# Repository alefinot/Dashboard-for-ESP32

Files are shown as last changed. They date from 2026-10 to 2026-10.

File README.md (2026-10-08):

# Dashboard++ for ESP32





[]()

**Dashboard++** is an ultra-high-performance, production-grade automotive digital instrument cluster and telemetry solution designed for motorcycles, cars, and custom electric/combustion vehicles powered by the **ESP32 WROOM-32** dual-core microcontroller.

Featuring a 4.0-inch ILI9488 TFT display (480×320 resolution) driven over a 60 MHz SPI bus using **LovyanGFX** with PROGMEM-mapped VLW fonts, Dashboard++ blends real-time multi-sensor fusion algorithms, sprite-based anti-aliased digit rendering, dirty-rendering optimizations, hysteresis-based dynamic CPU frequency scaling, persistent NVS configuration management, an Open-Meteo live weather widget, and a complete single-page Web application served over WiFi with REST API control, NVS backup/restore, and automatic cloud OTA pull.

---

## Technical Table of Contents
1. [Executive Overview](#executive-overview)
2. [System Architecture & Task Allocation](#system-architecture--task-allocation)
3. [Hardware Component Specifications](#hardware-component-specifications)
4. [Hardware Pinout Matrix](#hardware-pinout-matrix)
5. [Software Architecture & Mathematical Models](#software-architecture--mathematical-models)
   - [Dual-Source Speed Fusion & Odometer Engine](#1-dual-source-speed-fusion--odometer-engine)
   - [Anti-Aliased GFX Engine & 7-Segment Fonts](#2-anti-aliased-gfx-engine--7-segment-fonts)
   - [Piecewise Linear Fuel Calibration & Filtering](#3-piecewise-linear-fuel-calibration--filtering)
   - [Steinhart-Hart Coolant Temperature Math](#4-steinhart-hart-coolant-temperature-math)
   - [Fuel Economy & Performance Drag Timer](#5-fuel-economy--performance-drag-timer)
   - [Power Management & Dynamic CPU Scaling](#6-power-management--dynamic-cpu-scaling)
6. [Embedded Web UI & REST API Reference](#embedded-web-ui--rest-api-reference)
7. [NVS Configuration Parameter Reference](#nvs-configuration-parameter-reference)
8. [Codebase Architecture & File Map](#codebase-architecture--file-map)
9. [Build, Installation & Flashing Guide](#build-installation--flashing-guide)
10. [Simulation & Demo Mode](#simulation--demo-mode)
11. [License & Credits](#license--credits)

---

## Executive Overview

Dashboard++ replaces legacy analog or basic digital gauges with an automotive-grade telemetry console. Key capabilities include:

- **Dual Speed Fusion (Hall Effect + GNSS):** Dynamically fuses microsecond-level hardware interrupt pulses with NMEA GPS speed vectors, adjusting confidence based on satellite lock quality ($N_{\text{sat}}$) and cross-checking delta errors.
- **Sprite-Based Anti-Aliased Speed Rendering:** The main speed readout is pre-rendered to an off-screen LGFX_Sprite using a 120px VLW 7-segment digital font, then pushed to the display in a single DMA transfer — reducing SPI bus contention and eliminating per-digit draw calls.
- **PROGMEM VLW Font System:** All fonts (Conthrax SemiBold and DS-DIGIT variants) are compiled into flash as PROGMEM byte arrays (generated from the `.vlw` sources in `data/Fonts/` by `scripts/vlw_to_header.py`), loaded at build time via `loadVLWFont()` — zero DRAM per glyph, no runtime filesystem lookups.
- **Dirty-Rendering Frame Pipeline:** Element state tracking ensures only mutated visual regions are drawn to the SPI bus, with dedicated per-element refresh rate throttles for speed, satellite count, timer, battery, fuel economy, and average speed.
- **Configurable 7-Segment Digital Fonts:** 120px (sprite) and 28px (direct) seven-segment fonts with background "ghost digit" rendering (888 backdrop effect) and fully user-configurable integer and decimal digit boundaries for all telemetry counters.
- **Full Sensor Suite Integration:** Precise fuel level monitoring (20-point piecewise linear calibration table + EMA filtering), engine coolant thermistor telemetry (Steinhart-Hart equation), battery voltage divider monitoring, trip fuel economy tracking, **trip average speed**, and a **session max speed (Vmax)** readout display.
- **FreeRTOS Dual-Core Multitasking:** Strict core isolation — the continuous ~1.1KB/s GNSS UART stream is quarantined in its own Core 0 task (bulk ring-buffer read, bounded per tick, sitting below the WiFi stack), while the vehicle sensor suite and UI rendering run on Core 1, so a GPS stream backlog can never stall the dashboard or freeze any real-time value.
- **Embedded Web Management Portal:** Embedded single-page Web application accessible over SoftAP or local WiFi network featuring grouped card-based configuration UI with live search, real-time performance telemetry panel (FPS, CPU frequency/temp, RAM, flash storage), interactive sliders, color pickers, NVS backup/restore, web serial terminal stream, cloud OTA pull, and HTTP file upload OTA firmware updating.
- **Hysteresis-Based Dynamic CPU Scaling:** Three-state frequency governor (240/160/80 MHz) with hysteresis deadbands prevents oscillation, and thermal throttling automatically caps frequency at configurable warning/critical temperature thresholds.

---

## System Architecture & Task Allocation

The system leverages the ESP32's Xtensa dual-core processor via FreeRTOS tasks to guarantee deterministic sensor sampling without visual stuttering or UI delays.

```
┌─────────────────────────────────────────────────────────────────────────────────┐
│                            ESP32 WROOM-32 DUAL-CORE                             │
├────────────────────────────────────────┼────────────────────────────────────────┤
│    CORE 0  (GNSS Stream & Network)     │  CORE 1  (Vehicle Sensors & Display)   │
├────────────────────────────────────────┼────────────────────────────────────────┤
│┌──────────────────────────────────────┐│┌──────────────────────────────────────┐│
││ Task: GpsTaskCore0 (Prio 2, 10KB)    │││ Task: SensorTaskCore1 (Prio 2, 10KB) ││
││                                      │││                                      ││
││• UART2 @ 115200 bulk ring drain      │││• Hall Sensor GPIO33 ISR              ││
││  (readBytes() batch, 1024 B/tick cap)│││• ADC: Fuel (32), Temp (36), Bat (35) ││
││• TinyGPS++ NMEA + UBX NAV-PVT parse  │││• Fuel Economy & Accel Timer          ││
││• Speed Fusion & Odometer calc        │││• Trip Average Speed                  ││
││• GNSS Epoch Time Sync -> settimeofday│││• Safe Thread Sync via g_stateMutex   ││
││• Safe Thread Sync via g_stateMutex   │││                                      ││
││                                      │││• Safe Thread Sync via g_stateMutex   ││
││──────────────────────────────────────│││──────────────────────────────────────││
││ Task: WebTaskCore0 (Prio 1, 12KB)    │││ Main Loop (Priority 1)               ││
││                                      │││                                      ││
││• SoftAP (Dashboard_Config) & STA     │││• Dirty-Rendering Frame Pipeline      ││
││• WebServer HTTP Handlers             │││• LovyanGFX SPI Driver (60 MHz)       ││
││• ArduinoOTA Firmware Listener        │││• Sprite-Based Speed (120px VLW)      ││
││• Serial Log Streaming API            │││• Hysteresis CPU Scaling (80/160/240) ││
│└──────────────────────────────────────┘││• Auto Night-Mode Backlight PWM       ││
│                                        ││• Ignition Deep Sleep State Machine   ││
│                                        ││• Telemetry Logging to 4KB Ring       ││
│                                        │└──────────────────────────────────────┘│
└─────────────────────────────────────────────────────────────────────────────────┘
```

> [!NOTE]
> The GNSS task sits on Core 0 **below** the WiFi/HTTPD/LWIP stack on purpose: the module streams
> ~1.1KB/s continuously and the drain is I/O-gated at the byte arrival rate, so it can never
> out-run the stream. GPS is 1Hz-tolerant data, so if the network preempts the drain, only GPS
> values lag — the vehicle sensors and the screen are never touched.

> [!NOTE]
> The **weather fetch task** (Core 0, spawned by `startWeatherFetch()` on Core 1) polls the Open-Meteo
> API on a configurable interval (`WEATHER_REFRESH_MIN`) and stores the result in a dedicated
> `g_weatherData` struct. A 30 s guard asks a stuck fetch to abort (the fetch polls
> `weatherAbort` at its checkpoints and HTTP calls carry 8 s connect/read timeouts) so it unwinds
> and deletes itself rather than being killed with `vTaskDelete()`; while an aborted fetch is still
> alive, `startWeatherFetch()` refuses to stack a second one. A config save triggers an
> instant refetch with a 2 s retry backoff.

> [!NOTE]
> Every FreeRTOS task is started through `startTask()` in `src/main.cpp`, which checks the
> `xTaskCreatePinnedToCore()` return value, retries once on half the requested stack (a reduced
> stack usually fits and beats a missing subsystem) and, if that fails too, records the task in a
> `failedTasksMask` and logs it with the free heap. A task that cannot start is therefore named in
> the boot log instead of silently missing — the failure that used to show up only as a frozen
> heartbeat, no Web UI or dead sensors.

---

## Hardware Component Specifications

| Component | Part / Model | Protocol / Signal | Specifications |
| :--- | :--- | :--- | :--- |
| **Microcontroller** | ESP32-WROOM-32 | Xtensa 32-bit LX6 | Dual-core 240 MHz, 520 KB SRAM, 4 MB SPI Flash, RTC IO |
| **Display Panel** | ILI9488 TFT LCD (4.0") | SPI3 (16-bit RGB565) — SCLK GPIO18, MOSI GPIO23, CS GPIO5, DC GPIO27, RST GPIO14 (no MISO) | 480×320 pixels, 60 MHz SPI bus speed (clamped to 1–80 MHz), hardware CS/DC/RST |
| **Display Backlight** | LED Backlight (`BL_DISPLAY`, GPIO12) | LEDC PWM — pin-based `ledcAttach(BL_DISPLAY, 1000, 8)` | 1 kHz hardware PWM, 8-bit resolution (256 brightness levels), logarithmic fading; the LEDC channel is assigned by the arduino-esp32 3.x wrapper |
| **GNSS Module** | BZGNSS P25 Pro (u-blox M10) | UART2 (RX=GPIO16, TX=GPIO17) | 115200 baud (configurable), UBX NAV-PVT / NMEA 0183 stream (module is preconfigured — the firmware is receive-only), 10 Hz update rate, multi-constellation (GPS/GLONASS/BDS/Galileo), UTC epoch time synchronization |
| **Wheel Speed Sensor** | Hall Effect Interrupt | GPIO33 (Input Pullup) | Any-edge ISR stamps the edges; interval/filter logic runs on the sensor task, microsecond timing |
| **Fuel Level Sensor** | Marine Resistive Sender (capacitive touch removed in v1.3.6) | GPIO32 (ADC1_CH4) | Voltage divider behind an excitation resistor, ohm-domain calibration table (up to 20 points), oversampling + EMA smoothing, open/short detection |
| **Engine Temp Sensor** | NTC Thermistor (10k/100k) | GPIO36 (ADC1_CH0) | Analog 0–3.3V, Steinhart-Hart equation, voltage divider balance |
| **Battery Voltage** | Voltage Divider (5.7:1) | GPIO35 (ADC1_CH7) | Analog 0–3.3V, range 0–18.8V DC, sampled every 500 ms |
| **Power / Ignition** | Ignition Key Sense Line | GPIO4 | High=Ignition ON, Low=Power Lost → Animated Deep Sleep |

---

## Hardware Pinout Matrix

> For the board side of the same information — which connector/plug each signal lives on,
> with the connector pin numbers and the small-part roles — see
> [`hardware/PINOUT.md`](hardware/PINOUT.md).

| ESP32 Pin | Function Name | Peripheral Type | Signal Direction | Hardware Configuration & Notes |
| :---: | :--- | :--- | :---: | :--- |
| **GPIO0** | BOOT | Factory Reset | Input (Pullup) | `pinMode(0, INPUT_PULLUP)`; **hold BOOT 4 s, release, hold 4 s again** within the first 30 s after boot to wipe the config — the reliable path. The release in the middle is required because GPIO0 is shared with the serial adapter's DTR line through the auto-reset transistor: a PC that holds DTR asserted keeps GPIO0 low forever, and the old single 8 s hold wiped the config on every boot with nobody touching the board. The serial fallback (send `RESET` within the first 2 s of boot) is matched against a rolling 32-character window, so boot-log echo can no longer fill the capture and hide the command (issue #39) |
| **GPIO1** | Console TX | Debug Console | Output | `Serial.setPins(1, 3)` pins the console explicitly (arduino-esp32 3.x moved the UART1 default to GPIO26/27) |
| **GPIO3** | Console RX | Debug Console | Input | Same `Serial.setPins(1, 3)` call |
| **GPIO4** | `POWER_SENSE_PIN` | Power Sense | Input (No Pull) | Ignition sense line; triggers EXT0 RTC wake up from deep sleep |
| **GPIO5** | `CS_DISPLAY` | SPI Chip Select | Output | Hardware SPI CS for ILI9488 Display |
| **GPIO12** | `BL_DISPLAY` | Backlight PWM | Output | Pin-based `ledcAttach(BL_DISPLAY, 1000, 8)` — 1 kHz PWM, 8-bit resolution |
| **GPIO14** | `SPI_RST` | Display Reset | Output | Active-Low hardware reset line for ILI9488 |
| **GPIO16** | `GNSS_UART2_RX_PIN` | GPS Serial RX (UART2) | Input | Connected to the GNSS module TX pin. Receive-only: the firmware never transmits to the module |
| **GPIO17** | `GNSS_UART2_TX_PIN` | GPS Serial TX (UART2) | Output | Connected to the GNSS module RX pin; configured but idle - no UBX command is ever sent |
| **GPIO18** | `cfg.pin_sclk` | SPI Clock | Output | Hardcoded in `gfx.cpp` (SPI3_HOST), 60 MHz default |
| **GPIO23** | `cfg.pin_mosi` | SPI Master Out | Output | Hardcoded in `gfx.cpp`, LCD data/command stream |
| **GPIO25** | `TRIP_RESET_PIN` | Trip Reset Button | Input (Pullup) | Momentary push button to GND; hold `TRIP_RESET_HOLD_MS` to zero the trip stats (issue #17). Internal ~45 kΩ pull-up, no external parts |
| **GPIO27** | `SPI_DC` | Data / Command | Output | High = Data, Low = Command for ILI9488 controller |
| **GPIO32** | `FUEL_TOUCH_PIN` | Fuel sender input | Input | Dedicated ADC1 Channel 4 pin: 3V3 → `FUEL_EXC_RES_OHM` → GPIO32 → sender → tank ground (capacitive touch removed in v1.3.6) |
| **GPIO33** | `HALL_SENSOR_PIN` | Hall Interrupt | Input (Pullup) | Any-edge (`CHANGE`) hardware interrupt: the ISR timestamps both transitions, the filter chain validates them on the sensor task |
| **GPIO34** | `LIGHT_SENSOR_PIN` | Ambient Light | Input (No Pull) | LDR ambient light sensor for auto-brightness (calibrated via `/api/ambient/cal-dark` / `cal-bright`) |
| **GPIO35** | `BATTERY_SENSE_PIN` | Battery ADC | Input (No Pull) | Connected to 5.7:1 precision resistor divider node |
| **GPIO36** | `TEMP_SENSE_PIN` | Engine Temp ADC | Input (No Pull) | Connected to NTC thermistor / balance resistor divider node |

> [!IMPORTANT]
> GPIO32 is dedicated to the fuel ADC input to avoid pin-sharing conflicts with the GPIO33 Hall interrupt hardware line.

> [!NOTE]
> This matrix matches the code (`src/dashboard.h` pin defines and the hardcoded display SPI pins in `src/gfx.cpp`), which is the source of truth. The GNSS serial pair moved from GPIO25/26 to **GPIO16/17** during the pin-swap test and stayed there, which is what freed **GPIO25** for the trip-reset button; **GPIO26** stays free as the spare for a second button. Strapping pins (`GPIO0`, `GPIO2`, `GPIO5` = `CS_DISPLAY`, MTDI/`GPIO12`, MTDO/`GPIO15`) are deliberately not used for buttons — a button to GND can hold them the wrong way during reset and block boot. The display SPI bus has no MISO line (`cfg.pin_miso = -1`), and GPIO21/22 (former compass I²C) are unused.

---

## Software Architecture & Mathematical Models

### 1. Dual-Source Speed Fusion & Odometer Engine

Dashboard++ features a dual-source speed calculation engine that combines low-latency wheel rotation timing with absolute satellite GPS telemetry.

#### Hall Sensor Calculation & 5-Layer Defense Pipeline
Speed is derived from microsecond timing between consecutive interrupt pulses on GPIO33, protected by an end-to-end 5-layer defense pipeline that eliminates spark ignition EMI glitches, prevents baseline collapse during deceleration, and bounds rate-of-change to physical limits:

1. **Layer 1: Measured Pulse-Width Qualification (Glitch Filter):** Real wheel magnets hold GPIO33 LOW for hundreds of microseconds (one revolution at 200 km/h is still 29.7 ms long). High-frequency ignition coil ringing collapses back to HIGH within <10 µs. The GPIO ISR used to prove the width by busy-waiting `HALL_PULSE_MIN_US` and re-sampling `REG_READ(GPIO_IN1_REG)` **inside** the interrupt, which masked interrupts on that core for up to 1 ms per glitch (~86 bytes of GNSS RX at 115200 baud). Now the interrupt is `CHANGE` (both edges), the ISR only stamps the transition time into a 64-slot ring, and the qualification is *measured*: `rise − fall ≥ HALL_PULSE_MIN_US` (default 150 µs, WebUI-tunable, clamped to 10…1000 µs). A glitch is dropped before any interval logic runs, exactly as before, and the ISR stays at roughly a microsecond. Ring overflow drops the newest edge and is counted as `drop=` in the `HALL:` telemetry line; the accept latency is reported as `lag=`.
2. **Layer 2: Anti-Collapse Timing Baseline (Integer Guard) + Period Guard:** 100% integer timestamping and period guard with zero floating-point math, in the validation step that runs on the sensor task (`processHallEdges()`). When actively rolling, candidate intervals faster than $2\times$ previous speed ($gap \times 2 < last$) are dropped without updating `lastHallPulseTimeUs` or the stable baseline `hallStableIntervalUs`. This prevents spark bursts during braking from collapsing the guard baseline and producing >200 km/h spikes. The complementary upper bound is `HALL_PERIOD_GUARD`: an interval more than $N\times$ the last accepted one is dropped too (a wheel cannot slow $N$-fold in a single revolution; a genuine stop is handled by Layer 3 instead). $N = 1$ disables it.
3. **Layer 3: Standstill Detection, Buffer Purge & Deceleration Decay:** If time since the last pulse exceeds `STANDSTILL_TIMEOUT_US` (1.5 s), the wheel was stopped. The first pulse synchronizes the timing baseline, holds its odometer credit until a confirming pulse follows, and completely purges the history ring buffer. During deceleration, if elapsed time $dt$ since the last pulse exceeds $1.5\times$ the rotation period (plus the recorded accept latency `lag`, so deferred validation cannot make an on-time pulse look overdue), dynamic decay constrains speed smoothly to 0 km/h without mid-revolution diving.
   - **Layer 3b: Confirmed-Roll Speed Gate:** the purge in Layer 3 also disarms Layer 2 (which is conditioned on the rolling state) and leaves the median window with a single sample, so before this gate *one* accepted inter-edge gap became the displayed speed — two ignition-EMI edges 12 ms…1.5 s apart on a parked machine reported a plausible reading (100 ms → 59 km/h on a 1650 mm wheel). The speed output now stays at 0 until `HALL_CONFIRM_REVS` (3) consecutive accepted intervals agree pairwise within $2\times$ — the same physical bound Layer 2 uses while rolling. Cost: a genuine roll start is displayed two revolutions later (≈0.6 s at 12 km/h, ≈0.2 s at 30 km/h). Distance credits are unaffected (the odometer is guarded by the pending-anchor logic). Below ~4 km/h the 1.5 s standstill timeout already reports 0, so the usable low-speed floor does not change.
4. **Layer 4: Physical Slew-Rate Limiter (Max Accel / Decel):** Terrestrial motorcycles cannot exceed physical acceleration limits (~1.7g / 60 km/h/s) or emergency braking (~2.3g / 80 km/h/s). Clamping $\Delta V$ between update ticks (~20 ms) mathematically prevents instantaneous multi-hundred km/h jumps on the speedometer.
5. **Layer 5: Sensor Fusion Outlier Rejection:** In Sensor Fusion mode (2), if Hall speed reads $> V_{\text{gps}} + 30\text{ km/h}$ while GPS has a solid satellite lock, the Hall reading is rejected as an anomalous spike and the dashboard displays GPS speed.

#### Speed Source & Fusion Logic
The displayed speed source is selected by `SPEED_SOURCE_MODE`: `0`=Hall only, `1`=GPS only, `2`=Sensor Fusion (default).

In **Sensor Fusion mode (2)**, the engine dynamically balances both sensors:
- **Rock-Solid Standstill:** When $V_{\text{hall}} = 0$ and $V_{\text{gps}} < \text{GPS\_START\_KMH}$ (3.0 km/h), speed is forced to solid `0.0 km/h`, eliminating GPS drift at traffic lights.
- **Immediate Response:** As soon as wheel pulses arrive ($V_{\text{hall}} > 0$), speed is displayed immediately without clamping.
- **Dynamic Throttle Tracking:** When $|V_{\text{gps}} - V_{\text{hall}}| > \text{MAX\_SPEED\_DELTA\_KMH}$ (such as normal GPS lag during rapid acceleration), Hall is trusted directly so throttle response is never suppressed.
- **Dual Failsafe Redundancy:** If the Hall sensor fails or disconnects at speed, the system automatically falls back to valid GPS ($V_{\text{gps}} \ge 3.0\text{ km/h}$). If GPS signal is lost in a tunnel, Hall sensor carries 100% of the speed. Speed never drops to 0 while moving.
- **Dynamic Confidence Blending:** When both sensors are healthy and consistent ($\Delta V \le \text{MAX\_SPEED\_DELTA\_KMH}$):
$$C_{\text{sat}} = \text{constrain}\left(\frac{N_{\text{sat}} - N_{\text{min}} + 1}{N_{\text{opt}} - N_{\text{min}} + 1}, 0.0, 1.0\right)$$
$$C_{\delta} = \text{constrain}\left(1.0 - \frac{\Delta V - \Delta V_{\text{min}}}{\Delta V_{\text{max}} - \Delta V_{\text{min}}}, 0.0, 1.0\right)$$
$$W_{\text{gps}} = C_{\text{sat}} \cdot C_{\delta} \cdot 0.5$$
$$V_{\text{fused}} = (W_{\text{gps}} \cdot V_{\text{gps}}) + ((1 - W_{\text{gps}}) \cdot V_{\text{hall}})$$
Capping $W_{\text{gps}}$ at 0.5 ensures Hall sensor's zero-latency dynamic throttle/brake response is always preserved, while GPS anchors long-term tire wear accuracy.

#### Odometer Persistence Strategy
To protect the ESP32 NVS Flash memory from wear, distance accumulation runs continuously in RAM. The odometer writes to non-volatile storage **only after accumulating a full 1.0 km increment**:
$$\Delta D_{\text{ram}} \ge 1.0\text{ km} \implies \text{Preferences.putDouble("odo", } D_{\text{total}}\text{)}$$

**Sharing the odometer across cores.** The odometer is a 64-bit `double`, and a 64-bit load/store on ESP32 is two 32-bit bus cycles: a read that lands between the two halves of a write returns a mixture of two different distances. The totals therefore live file-local in `src/sensors.cpp` and every other task reaches them through the locked accessors `odoGet()`, `odoSet()`, `odoAdd()` (read-modify-write in one critical section), `odoLastSaved()` and `odoMarkSaved()`, guarded by a dedicated spinlock (`odoMux`) — deliberately *not* `g_stateMutex`, so the display never waits behind sensor or NVS work and the critical sections stay a few instructions long. The accessors never write flash; the 1 km wear discipline above is unchanged.

#### UBX Frame Parser (receive-only)

The module streams UBX and NMEA on the same UART, so `src/sensors.cpp` runs a byte-at-a-time state machine (`ubxParseByte`) alongside TinyGPS++: it locks onto `0xB5 0x62`, reads class/id/length, seeds both Fletcher-8 accumulators by stepping through each header byte individually, and hands a checksum-valid NAV-PVT to the NMEA side. It never transmits anything (see the receive-only rule).

- **Length is honoured, including zero.** A zero-length payload goes straight to the checksum states — entering the payload state with `len = 0` used to consume `CK_A`/`CK_B` as payload, corrupt the accumulators and raise a spurious `CKFAIL`, leaving the parser to resync by luck on the next `0xB5` (issue #33).
- **Oversize frames are dropped at the header** (`len > 92`) rather than overflowing the payload buffer, and a bad checksum drops exactly one frame before resyncing.
- **Counters, not silence:** `ubxSyncSeen`, `ubxCkFail`, `ubxOversize` are reported in the GPS debug telemetry so a framing problem is visible instead of looking like lost satellites.
- **Checked offline:** `python scripts/verify_ubx_parser.py` runs a host replica of the state machine against hand-built frames — NAV-PVT (92 B), ACK (10 B), zero-length, poisoned checksum, garbage/false-sync, oversize, back-to-back frames — and asserts that the old zero-length path still fails, so the regression cannot come back unnoticed.

---

### 2. Anti-Aliased GFX Engine & 7-Segment Fonts

Graphics rendering is built on `LovyanGFX` with specialized antialiasing routines and a PROGMEM-mapped VLW font system (compiled into flash — no runtime filesystem lookups, zero DRAM per glyph).

#### Text Bounds Contract (`getTextBounds`)

`LGFX_ST7789_4::getTextBounds()` (declared in `src/dashboard.h`, defined in `src/gfx.cpp`) reports **advance-based** bounds, not ink bounds: `w` is `textWidth()` (the advance the string consumes), `h` is the font line height, `y1` is `-baseline`, and **`x1` is always `0` by contract** (issue #44). Every layout path — 7-segment digit cells, the weather/accel badges, the centred splash and signature strings — places text on advances, and the `- x1` terms those expressions carry are the documented slot where a real per-glyph left bearing would flow through, not a live correction. Code must not treat `x1` as a measured bearing; if ink bounds are ever needed, a separate helper gets added rather than these semantics changing. The `digitXOff[]` / `ds15_digitXOff[]` tables fed from it are therefore advance-only offsets by construction.

#### Alpha Blending Math
Sub-pixel anti-aliased primitives draw edges with fractional coverage $\alpha \in [0, 1]$. Color blending uses fast integer arithmetic:
$$R_{\text{out}} = \lfloor (R_{\text{bg}} \cdot (256 - a) + R_{\text{fg}} \cdot a) \gg 8 \rfloor$$
$$G_{\text{out}} = \lfloor (G_{\text{bg}} \cdot (256 - a) + G_{\text{fg}} \cdot a) \gg 8 \rfloor$$
$$B_{\text{out}} = \lfloor (B_{\text{bg}} \cdot (256 - a) + B_{\text{fg}} \cdot a) \gg 8 \rfloor$$

#### Sprite-Based Speed Rendering
The main speed display is rendered to an off-screen `LGFX_Sprite` using the VLW 120px 7-segment digital font. Ghost digits (888 backdrop) and active digits are drawn once per frame into the sprite, then pushed to the display in a single DMA transfer — drastically reducing SPI bus transactions compared to per-digit draw calls.

#### VLW Font System
All typography is compiled into flash as PROGMEM byte arrays (`include/*.h`, generated from the `.vlw` sources in `data/Fonts/` by `scripts/vlw_to_header.py`):
- `DS-DIGIT_120px.vlw` → `DS_DIGIT_120px_vlw.h` — Main speed readout (sprite-rendered)
- `DS-DIGIT_28px.vlw` → `DS_DIGIT_28px_vlw.h` — Secondary digits (time, odometer, satellite, battery, fuel economy, average speed)
- `Conthrax_SemiBold_28px.vlw` → `Conthrax_SemiBold_28px_vlw.h` — Section headers and badges
- `Conthrax_SemiBold_16px.vlw` → `Conthrax_SemiBold_16px_vlw.h` — Unit labels and sidebar text
- `Conthrax_SemiBold_10px.vlw` → `Conthrax_SemiBold_10px_vlw.h` — Micro labels (AVG badge, IST badge)

Legacy compiled-in GFX font bitmaps (`Conthrax_SemiBold4pt7b`, `Conthrax_SemiBold7pt7b`) are retained as fallbacks for the badge/label sizes.

---

### 3. Marine Resistive Fuel Sender: Divider, Ohm-Domain Table & Filtering

Fuel level is read from a standard marine resistive sender wired as a voltage
divider on `FUEL_TOUCH_PIN` (GPIO32). The capacitive pad this input used to carry
is gone; the pin is now a plain ADC input (issue #18):

```
3V3 ─── FUEL_EXC_RES_OHM ─── GPIO32 (ADC1_CH4) ─── sender ─── tank ground
```

#### From ADC code to ohms
`FUEL_OVERSAMPLE` conversions are averaged into a raw code $\bar{S}$ (software
oversampling — the core exposes no hardware averaging for this pin), turned into
a voltage with `FUEL_ADC_VREF` (the 3.3 V rail — since issue #55 it is not a Web
UI field any more), and the sender resistance is recovered from the divider:

$$V = V_{\text{ref}} \cdot \frac{R_{\text{sender}}}{R_{\text{sender}} + R_{\text{exc}}} \qquad\Rightarrow\qquad R_{\text{sender}} = R_{\text{exc}} \cdot \frac{V}{V_{\text{ref}} - V}$$

The calibration table (`fuelCalOhms`) stores **ohms, not ADC codes**. That is
what makes any sender standard work on the same firmware — SAE **10–180 Ω**
(low = empty), European/VDO **240–33 Ω** (high = empty), GM **0–90 Ω** — and it
means a captured table still means the same thing after the excitation resistor
(or the sender) is swapped. `FUEL_OHM_EMPTY` / `FUEL_OHM_FULL` describe the
sender: they size the exciter, define the fault band, and pre-fill the table
ramp; they do not replace the table.

#### EMA + piecewise interpolation
Smoothing stays in the ADC-code domain (linear, and the same domain the table was
captured against), then the ohm value walks the table:
$$\bar{S}_t = (\alpha \cdot S_t) + ((1 - \alpha) \cdot \bar{S}_{t-1}) \qquad \alpha = \texttt{FUEL\_FILTER\_ALPHA}\ (default{=}0.08)$$
Given $N$ table points $T[0 \dots N-1]$ mapped to tank slots $0 \dots N-1$, find
segment $i$ containing $R_{\text{sender}}$:
$$L_{\text{fuel}} = i + \left(\frac{R_{\text{sender}} - T[i]}{T[i+1] - T[i]}\right)$$
$$\text{FuelPercentage} = \text{constrain}\left(\left\lfloor \frac{L_{\text{fuel}}}{N - 1} \times 100 \right\rfloor, 0, 100\right)$$

The traversal direction is taken from the table's two ends, so a rising (SAE) and
a falling (European) sender are both handled without a mode switch.

#### Sender fault detection
The failure that makes a self-built sender useless is an open line that still
looks like a plausible reading, so the input is classified every sample and shown
in the Web UI instead of being turned into a tank level:

| Condition | Reported as |
| :--- | :--- |
| `FUEL_INPUT_ENABLED` off | **no input** — gauge pinned at 0, a floating pin never invents a level |
| pin within 0.5 % of the rail, or $R > 3 \times$ the entered full/empty maximum | **open circuit** — sender unplugged, wire broken, arm off the pivot |
| $R$ below `min(EMPTY, FULL)` by more than `max(5 Ω, 25 %)` | **shorted input** — signal wire on ground |

Demo mode drives the same pipeline: the simulated level is converted back through
the calibration table into a divider code and read forward again, so the table,
divider math and fault band are exercised with no hardware fitted (rule 20).

#### Excitation resistor sizing
$R_{\text{exc}}$ is a trade: the geometric mean of the sender range spreads the
span over the most volts, but pushes more current through the sender element. The
Web UI suggests the best E12 value for the entered range under a **15 mA** sender
current budget and keeps the top of the span below 2.6 V, because a reading
pinned near the rail is indistinguishable from an open circuit. For the shipped
10–180 Ω default that suggestion is 220 Ω — the same value the firmware ships
with — giving a 1.34 V span at 14.3 mA.

Check the whole chain on a host with `python scripts/verify_fuel_ohms.py`
(divider round-trip, both conventions, resolution per tank slot, demo round-trip,
fault band, exciter suggestion).

---

### 4. Steinhart-Hart Coolant Temperature Math

Engine temperature is measured via an NTC thermistor connected in a resistor divider configuration with a balance resistor $R_{\text{balance}}$ (default=10,000 $\Omega$).

#### Voltage Divider Resistance Calculation
$$V_{\text{out}} = \text{ADC}_{\text{raw}} \times \left(\frac{3.3}{4095}\right)$$
$$R_{\text{ntc}} = R_{\text{balance}} \times \left(\frac{V_{\text{out}}}{3.3 - V_{\text{out}}}\right)$$

#### Steinhart-Hart B-Parameter Equation
$$T_{\text{Kelvin}} = \left( \frac{1}{\beta} \cdot \ln\left(\frac{R_{\text{ntc}}}{R_{\text{room}}}\right) + \frac{1}{T_{\text{room}}} \right)^{-1}$$
$$T_{\text{Celsius}} = T_{\text{Kelvin}} - 273.15$$
where $R_{\text{room}} =$ `NTC_R25` (default=10,000 $\Omega$), $T_{\text{room}} = 298.15\text{ K}$ ($25^\circ\text{C}$), and $\beta =$ `NTC_BETA` (default=3950). A fixed `NTC_TEMP_OFFSET` (°C, default=0.0) is added to the result to correct a systematic reading bias.

#### WebUI Sensor Calibration
The **Sensors Tuning** WebUI card calibrates the two analog sensors against a reference, using the live `/api/live` snapshot the page polls once per second (no raw-ADC conversion needed):
- **Fuel level Sensor** — the live sender resistance (Ω) is shown next to a fault state (`open` / `shorted` / `out of range` / `no sender`). Two ways to build the table (`fuelCalOhms`): **Fill from empty/full ohm** pre-fills a linear ramp from `FUEL_OHM_EMPTY` to `FUEL_OHM_FULL` (a good start, no driving needed), or drive the tank through its levels and **Capture** the live reading into each slot — slot `0` = empty, slot `N-1` = full. Changing the point count regenerates the ramp. The card is titled without the pin number (issue #55), and the excitation-resistor suggestion is computed from the empty/full ohms on the page plus the fixed 3.3 V rail.
- **Speedometer** — `SPEED_SOURCE_MODE`, `SPEED_SOURCE_HOLD_MS`, the two hall-vs-GPS deviation bands (`GPS_MIN_DEV_KMH`, `MAX_SPEED_DELTA_KMH`), the GPS start/stop pair (`GPS_START_KMH`, `GPS_STOP_SETTLE_MS`) and the wheel-signal filters (`HALL_MEDIAN_SAMPLES`, `HALL_PERIOD_GUARD`, `HALL_PULSE_MIN_US`), in that order (issue #56). The GNSS hardware rows (baud, satellite counts) stay in the GPS block.
- **Engine Temperature** — the live reading is shown; type a reference temperature and press **Apply** to set `NTC_TEMP_OFFSET`. `NTC_R25`, `NTC_R_BALANCE` and `NTC_BETA` are under **Advanced**.
- **Battery Voltage** — the live reading is shown; type a reference voltage (e.g. a multimeter) and press **Apply** to set `BATTERY_OFFSET`. `BATTERY_SCALE` (divider ratio) is under **Advanced**.
- Calibrating against a live reading means no raw-ADC arithmetic in the browser: the offset is derived on the device from the value it is currently seeing.

---

### 5. Fuel Economy & Performance Drag Timer

#### Instantaneous & Trip Fuel Economy
- **Trip Average (KM/L):** $KM/L_{\text{avg}} = \frac{D_{\text{trip}}}{C_{\text{consumed}}}$. The trip is zeroed only by an explicit trip reset — the physical button on GPIO25, `POST /api/trip/reset`, or a factory reset — never by a detected refuel (issue #17). A fuel-level rise still re-anchors the consumption baseline so the average stays sane, but it leaves the trip distance and the averages alone.
- **Instantaneous (KM/L):** Calculated across a 3-second sliding window:
  $$KM/L_{\text{inst}} = 0.4 \cdot \left(\frac{\Delta D_{3\text{s}}}{\Delta C_{3\text{s}}}\right) + 0.6 \cdot KM/L_{\text{inst, prev}}$$
- **Trip Average Speed (KM/H):** $V_{\text{avg}} = \frac{D_{\text{trip}}}{t_{\text{elapsed}}}$, displayed in the bottom row alongside fuel economy readouts.
- **Session Max Speed (Vmax):** The highest fused/filtered speed reached this power-on session; held on screen until the next reboot (RAM-only, no NVS persistence, no manual reset). Rendered as the **MAX** icon in the bottom row — same 28px 7-segment structure as the Instant KM/L readout — in MPH under imperial. Controlled by `SHOW_ELEMENT_MAX_SPEED`, `OFFSET_MAX_SPEED_X/Y`, `ALIGN_MAX_SPEED`, `MAX_SPEED_INT_DIGITS`, `MAX_SPEED_DEC_DIGITS`, and the `REFRESH_MAX_SPEED_MS` redraw throttle.

#### Acceleration Performance Timer
Measures time taken to accelerate between configured speed thresholds (`ACCEL_START_SPEED` to `ACCEL_TARGET_SPEED`, e.g., 0–50 km/h or 0–100 km/h) using a 3-state state machine with configurable timeout (`ACCEL_MAX_TIME`, default=30s):

```
  ┌─────────┐    Speed >= StartSpeed     ┌─────────┐
  │  READY  │ ─────────────────────────> │ RUNNING │
  └─────────┘                            └─────────┘
       ▲                                      │
       │ Speed < Start (Reset)                │ Speed >= TargetSpeed OR Timeout
       └──────────────────────────────────────┼───────────────────────┐
                                               ▼                       │
                                         ┌──────────┐                  │
                                         │ FINISHED │ <────────────────┘
                                         └──────────┘
```

---

### 6. Power Management & Dynamic CPU Scaling

To balance processing performance, power consumption, and thermal stability, Dashboard++ includes dynamic CPU management and ignition sensing.

#### Hysteresis Dynamic Scaling Matrix

The governor uses a 3-state machine with hysteresis deadbands to prevent frequency oscillation:

```
                      ┌──────────────────────────────┐
                      │ Read Current Measured FPS &  │
                      │ Die Temp (temperatureRead()) │
                      └──────────────┬───────────────┘
                                     │
                     Is ENABLE_DYNAMIC_CPU true?
                     ├─── NO  ──> Set MANUAL_CPU_FREQ (80 / 160 / 240 MHz)
                     └─── YES ──> Check current state:
                                    ├── State = 240 MHz:
                                    │    └── FPS > 85% Target → 160 MHz
                                    │    └── else → stay at 240 MHz
                                    ├── State = 160 MHz:
                                    │    ├── FPS < 65% Target → 240 MHz
                                    │    ├── FPS > 95% Target → 80 MHz
                                    │    └── else → stay at 160 MHz
                                    └── State = 80 MHz:
                                         ├── FPS < 45% Target → 240 MHz
                                         ├── FPS < 70% Target → 160 MHz
                                         └── else → stay at 80 MHz
                                    │
                                    └── Apply Thermal Throttling:
                                          ├── Temp >= CRIT (70°C): Force 80 MHz
                                          └── Temp >= WARN (60°C): Cap at 160 MHz
```

#### Ignition Loss & Deep Sleep Transition
When `ENABLE_POWER_SENSE` is enabled and `POWER_SENSE_PIN` (GPIO4) stays **continuously LOW for `POWER_SENSE_OFF_MS`** (default 10 s, 500–120000 ms):
1. Plays goodbye screen animation (`showGoodbyeScreen(true)`).
2. Fades display backlight down to 0% via LEDC PWM.
3. Configures RTC EXT0 wake-up trigger on GPIO4 (High level).
4. Invokes `esp_deep_sleep_start()`.

The line is debounced in software (`powerSenseOffConfirmed()` in `src/sensors.cpp`): the timer restarts on every HIGH, so ignition bounce, a load-dump dip or a flaky ground of a few milliseconds up to several seconds cannot stall the GPS/odometer task or put the unit to sleep (issue #26). A single LOW sample used to be enough. Side effect: key-off costs `POWER_SENSE_OFF_MS` of live current draw before the goodbye screen and sleep; wake behaviour is unchanged (EXT0 on GPIO4 going HIGH).

---

## Embedded Web UI & REST API Reference

Dashboard++ embeds a single-page management portal directly into flash memory (`index_html`).

### WiFi Network Connectivity
- **SoftAP Mode:** Emits AP SSID `Dashboard_Config` (Default IP: `192.168.4.1`). Always up alongside the client connection (`WIFI_AP_STA`), secured by `AP_PASSWORD` (empty or 8–63 characters).
- **Multi-SSID Client Mode:** Stores up to 5 networks. They are tried in slot order, and the search **never expires** — a failed cycle is simply followed by another one, forever (there is no search-policy parameter to set). The order is **automatic**: when a network joins, it is moved to slot 0, so the network this unit actually reached last is the first one tried after a reboot or a dropout — no hand-ordered “primary / fallback 1…4”. Credentials are only ever removed by an explicit **Forget**; being out of range is the normal state for a vehicle and never deletes a network by itself.
- **Phone-style network picker (Web UI → Network → Wifi):** press **Scan Networks**, tap the network, type the passphrase once. Open networks join without a password, a network that is already stored reconnects without asking for it again, and a hidden network is added by name. The scan is a cached list of the 30 strongest SSIDs (channels 1–13); it is never refreshed automatically, because a scan moves the radio off its working channel — it runs when asked and after a failed search cycle. With all five slots full the device refuses to guess: the UI asks which stored network may be replaced.

> [!IMPORTANT]
> **Access model (deliberate).** The config portal and the REST API have **no login** — access control is the Wi-Fi itself. `AP_PASSWORD` must be empty or 8–63 characters; a shorter value is rejected and the default (`12345678`) is restored, so the hotspot can never come up with a password the ESP32 silently refused. **Change that default before using the dashboard on a public network**: anyone who joins the hotspot (or reaches the dashboard's LAN IP) can change settings and flash firmware.

### Web UI Features
The management portal features a modern grouped card-based layout:
- **Collapsible sections** with smooth accordion animations (non-JS fallback)
- **Live search bar** to filter configuration parameters across all sections
- **Autosave** triggered 2 seconds after any input change
- **Visible checkboxes** (UI Layout → Screen Elements) control only what is drawn on the display; sensors, GPS, odometer and every calculation keep running whether the element is visible or not, so hiding a readout never stops the data behind it
- **Advanced Mode** switch in the header reveals the technical parameters, so the common setup path stays short (see `ADV_MODE`)
- **Color pickers** with inline preview for all UI color values
- **Slider + number inputs** with mouse-wheel scroll protection for all range parameters
- **XY offset controls** with linked sliders for UI element positioning
- **Real-time performance panel** displaying FPS, CPU frequency/temperature, RAM usage, flash storage utilization, and live serial output monitor
- **Weather Widget group** with city, latitude/longitude, refresh interval, locale, and a day/night icon
- **Ambient light calibration** (dark / bright reference points)
- **Cloud OTA pull** controls (enable, URL) with live status polling
- **OTA firmware upload** via file picker
- **NVS backup/restore** (export downloads `GET /api/config` as `dashboard_backup.json`, import posts it back to `POST /api/config`)

### REST API Endpoints

| Endpoint | Method | Description | Request Payload / Params | Content-Type |
| :--- | :---: | :--- | :--- | :--- |
| `/` | `GET` | Serves pre-gzipped single-page Web UI | None | `text/html` |
| `/debug` | `GET` | Dump first bytes of the pre-gzipped UI buffer (build sanity check) | None | `text/plain` |
| `/api/config` | `GET` | Exports complete NVS configuration plus read-only `build_version` | None | `application/json` |
| `/api/config` | `POST` | Updates NVS parameters and applies changes; on a save where N values could not be written the answer carries `nvsErrors: N`, `nvsFailedKeys: "KEY,…"` and `nvsAvailable` (free NVS entries) | Config JSON object | `application/json` |
| `/api/wifi/scan` | `GET` | Cached Wi-Fi scan plus the stored networks: `scanning`, `ageMs`, `count`, `max: 30`, `nets[]` (`ssid`, `rssi`, `ch`, `auth`, `authName`, `saved`) and `saved[]` (`slot`, `ssid`, `connected`). Reading it never touches the radio | None | `application/json` |
| `/api/wifi/scan` | `POST` | Queues a background scan of channels 1–13 (the radio leaves its channel for a few seconds, which is why the firmware never scans on its own); poll `GET` for the result | None | `application/json` (`{"status":"requested"}` / `{"status":"scanning"}`) |
| `/api/wifi/join` | `POST` | Stores one network and searches for it immediately. An SSID already stored keeps its slot (with no `pass` field the stored passphrase is reused, not blanked); otherwise the first free slot is used. With all five taken the answer is `status:"full"` plus the stored list, and re-sending with `"slot":n` names the network to displace | `{"ssid":"…","pass":"…"}` — `pass` omitted = reuse stored / open network; `"slot":n` = overwrite that slot | `application/json` (`status`, `slot`, `ssid`, `nvsOk`, `overwrite`) |
| `/api/wifi/forget` | `POST` | Removes one stored network from RAM and NVS and restarts the search. Credentials are never dropped by the device on its own | `{"slot":n}` (0–4) | `application/json` (`status`, `slot`, `ssid`, `nvsOk`) |
| `/api/time` | `POST` | Syncs system clock from browser | JSON body `{"timestamp":1700000000}` (integer epoch s; must fall in 2020–2100) | `application/json` (`{"status":"ok"}` / `400` with reason when out of range) |
| `/api/odo` | `GET` | Reads odometer distance in km | None | `application/json` |
| `/api/odo` | `POST` | Sets odometer distance | `{"km": 123.45}` | `application/json` |
| `/api/trip/reset` | `POST` | Zeros the trip stats (same reset as the GPIO25 button); the odometer and session max speed are untouched | None | `application/json` |
| `/api/reboot` | `POST` | Triggers graceful device restart | None | `text/plain` |
| `/api/sleep` | `POST` | Triggers immediate deep sleep | None | `text/plain` |
| `/api/reset` | `POST` | Factory reset — clears the `cfg` namespace; WiFi credentials and the odometer survive | None | `text/plain` |
| `/api/ambient` | `GET` | Reads raw ambient light sensor value | None | `application/json` |
| `/api/sensors` | `GET` | Reads calibrated battery voltage (`v`) and coolant temperature (`t`) | None | `application/json` |
| `/api/fuel` | `GET` | Reads the fuel input: `raw` averaged ADC code, `liters`, `pct`, `ohm` sender resistance, `st` input state (0 = disabled, 1 = ok, 2 = open circuit, 3 = shorted) | None | `application/json` |
| `/api/live` | `GET` | Single 1 Hz snapshot for the Web UI's live readings: `ambient`, `odo` (km), `fuel_raw`, `fuel_ohm`, `fuel_st`, `volts`, `temp`. One response feeds all five cells, so they always show the same instant | None | `application/json` |
| `/api/ambient/cal-dark` | `POST` | Sets dark-reference ambient light value (auto-brightness floor) | None | `application/json` (`{"status":"ok"\|"saved-ram-only","value":N}` — `saved-ram-only` means the value is applied but the NVS write failed) |
| `/api/ambient/cal-bright` | `POST` | Sets bright-reference ambient light value (auto-brightness ceiling) | None | `application/json` (same shape as `cal-dark`) |
| `/api/ota` | `POST` | Over-The-Air firmware binary upload | Binary `.bin` payload | `multipart/form-data` |
| `/api/ota/pull` | `POST` | Triggers cloud OTA pull (checks `OTA_PULL_URL`) | None | `text/plain` |
| `/api/ota/check` | `GET` | Reports cloud OTA pull state (`enabled`, `url`, `current_version`, `build_version`, `version_override`, `previous_version`, `status`) | None | `application/json` |
| `/api/serial` | `GET` | Streams internal 4 KB ring buffer logs | None | `text/plain` |
| `/api/perf` | `GET` | Live telemetry (CPU, Heap, task stack headroom, FPS, WiFi, partitions), plus the web task's own timing: `web_serve_ms_last` / `web_serve_ms_max` (what one `handleClient()` pass costs) and `web_slow_iters` (loop iterations over 100 ms) | None | `application/json` |
| `/api/health` | `GET` | Health probe: heap, FPS, partition layout and the NVS entry budget (`nvs_bytes`, `nvs_entries_used` / `_available` / `_total`) | None | `application/json` |
| `/api/boot` | `GET` | Boot/reboot forensics (reset reason, storm, last-reboot tag, heap watermark). `reset_reason` covers the whole core enum — `POWERON`, `EXT`, `SW (clean restart)`, `PANIC (crash/abort)`, `INT_WDT`, `TASK_WDT`, `WDT (other)`, `DEEP_SLEEP_WAKE`, `BROWNOUT`, `SDIO`, `USB`, `JTAG`, `EFUSE_ERR`, `PWR_GLITCH`, `CPU_LOCKUP`, `UNKNOWN`; anything unmapped prints `RST_<n>` (issue #42) | None | `application/json` |

---

## NVS Configuration Parameter Reference

Dashboard++ keeps every configuration parameter as one row of a single table, `CFG_TABLE` in `src/config.cpp`: the C++ global, the JSON key, the NVS key, the default, the allowed band and the kind (`CK_INT` / `CK_UINT` / `CK_FLT` / `CK_BOOL` / `CK_STR` / `CK_SECRET`) all on one line. `processConfig()` walks that table in its three modes — boot load, JSON serialize (`GET /api/config`) and restore/save (`POST /api/config`) — across 197 parameters (192 regular + 5 WiFi secrets), plus the fuel-calibration table kept beside it.

### Numeric Range Validation (issue #21)

Every numeric parameter carries an explicit **known-good band** in its `CFG_TABLE` row in `src/config.cpp` (`lo`/`hi` for `CK_INT` / `CK_UINT`, `flo`/`fhi` for `CK_FLT`) — that table is the single source of truth. The band is enforced on **all three write paths** (boot load, `POST /api/config`, and config restore): an out-of-range value is **clamped to the nearest end of the band, logged by name, and the clamped value is what gets written to NVS** — a bad value never reaches the running system, and a restore is never rejected outright because one field is off.

- **Non-finite floats** (`nan`, `inf`) fall back to the parameter's default rather than poisoning a calculation.
- **Cross-field rules** are repaired after the per-field clamps, in one place (`sanitizeConfigPairs()`): `TEMP_BAR_MIN < TEMP_BAR_MAX`, `TEMP_BAR_MIN <= TEMP_WARN_LOW <= TEMP_WARN_YEL <= TEMP_WARN_RED <= TEMP_BAR_MAX` (the three temp color fade points, repaired cold→hot so a band can never flip direction), `FUEL_WARN_RED <= FUEL_WARN_YEL` (fuel is mirrored — it turns red *below* its marker), `LIGHT_SENSOR_DARK_VAL < LIGHT_SENSOR_BRIGHT_VAL`, `MIN_SATELLITES <= OPTIMAL_SATELLITES`, `CPU_THROTTLE_TEMP_WARN <= CPU_THROTTLE_TEMP_CRIT`.
- **Enumerated parameters** are snapped to the nearest legal step: `GPS_BAUD` to a standard u-blox rate (1200…921600), `MANUAL_CPU_FREQ` to 80 / 160 / 240 MHz. `DISPLAY_ROTATION` is masked to 0–3, `WHEEL_CIRCUMFERENCE_MM` has always been floored at 1 (it is a divisor).
- **Fuel calibration table** (`fuelCalOhms`) cells are clamped to the sender band 0–100000 Ω on load and on restore. The table is in **ohms** since issue #18 (it used to be raw ADC codes under the name `touchTable`); old `touchTable` values in a backup are ignored rather than re-injected as ohms. The table is also required to be **monotonic in one direction** (the direction its first and last entries already imply): out-of-order points are sorted by `repairFuelTable()` on boot load and on save, written back to NVS, and named in the log, because a gap in the ramp would otherwise freeze the needle (issue #19). The gauge walk in `src/sensors.cpp` carries a second layer — a reading that matches no segment parks on the nearer end and logs once every 5 s instead of leaving the last value in place.
- The **WebUI mirrors the same bands** so a bad entry is caught before it is posted: numeric inputs get `min`/`max` from a `FIRMWARE_LIMITS` table generated out of `config.cpp` (`python scripts/make_webui_limits.py` regenerates it after any band change), an out-of-range entry is corrected in the box and listed in the save message, and an emptied numeric box falls back to its default instead of posting a blank (which the device used to read as `0`).

Bands are also checked offline by `python scripts/verify_config_ranges.py`: every numeric parameter must have a band, no shipped default may fall outside its own band, and the cross-field rules must hold for the factory values.

### NVS Access, Locking & Write Errors (issue #32)

ESP-IDF's NVS layer has its own internal locking, so a torn write is unlikely — what is *not* protected is the session. Two tasks opening and closing the same namespace independently can still collide: one task's `end()` closes the handle the other is still using, which comes back as `ESP_ERR_NVS_*` from `putInt()`/`putString()` and shows up as a setting that quietly reverted after a reboot. The old code took `prefsMux` at some call sites and not at others, so the protection depended on which file the code happened to live in.

- Every namespace open now goes through **`NvsSession`** (`src/dashboard.h`): an RAII wrapper that holds `prefsMux` for the whole `begin()`/`end()` pair, logs when a namespace cannot be opened, and closes on scope exit so an early return cannot leak the handle. It skips the lock while `prefsMux` is still `NULL` (early boot, single-threaded). The long-lived `preferences` object for the `dashboard` namespace keeps its explicit `prefsMux` pairs.
- **Write results are checked.** `nvsWriteFailed(key, esp_err_t)` logs the failing key with `esp_err_to_name()`; the table-driven save counts them (`cfgApply()` bumps `cfgNvsWriteErrors` for every row that fails) and a save ends with `Config save: N parameter(s) failed to reach NVS … they will revert on reboot` instead of pretending nothing happened. The same check covers the fuel-table writes, the factory-reset credential restore, the bootinfo writes and the ambient calibrations.
- **A failed read is not a default.** Where an unreadable NVS would previously have produced "no value" and triggered a factory seed, the seed is now skipped with a log line — a flash that cannot be read must never be answered by overwriting it.
- **Factory defaults are the table.** On first boot (`CFG_VER` missing or below 5) the seed writes each `CFG_TABLE` default straight into NVS and RAM (`cfgSeedDefaults()`, one `NvsSession` for the whole pass) — there is no second copy of the defaults in flash and no `JsonDocument` to build one. The WiFi credentials are deliberately not seeded, so a lost `CFG_VER` stamp can never strand a unit without a network, and the fuel ramp is rebuilt from the seeded `FUEL_OHM_EMPTY`/`FUEL_OHM_FULL` only when the stored table is not already the factory ramp.
- `prefsMux` is a plain (non-recursive) mutex: nothing inside a locked NVS region may open NVS itself.

### Key Configuration Categories

#### System & Performance
- `TARGET_FPS` (default=60): Desired display refresh rate, **5–120 FPS** (band-checked on load and in the Web UI). It sets the derived `DISPLAY_REFRESH_MS` frame budget (120 → 8 ms, 60 → 16 ms, 5 → 200 ms); values above what the SPI panel can carry simply drop the FPS counter rather than saturating the display core (issue #36).
- `SPI_BUS_SPEED` (default=60000000): SPI bus frequency in Hz. Accepted range **1000000–80000000** (1–80 MHz; WebUI shows MHz). Out-of-range values are clamped on load/save — a `0` or a negative (wrapped) value would otherwise feed LovyanGFX a degenerate clock divider and blank the panel. The read clock is derived as `SPI_BUS_SPEED × 8/5`, computed in 64-bit and clamped to the same band.
- `ENABLE_DYNAMIC_CPU` (default=false): Toggles automatic CPU frequency scaling (hysteresis-based).
- `MANUAL_CPU_FREQ` (default=240): Fixed CPU clock frequency (80, 160, or 240 MHz) used when `ENABLE_DYNAMIC_CPU` is off. The value is snapped to the nearest legal step, and every `setCpuFrequencyMhz()` call now checks its result — a refused switch logs `CPU: refused to switch to …MHz` instead of claiming a frequency the chip never switched to (issue #34).
- `ENABLE_CPU_THROTTLE` (default=true): Enables thermal frequency capping.
- `CPU_THROTTLE_TEMP_WARN` (default=60): Warning temperature threshold in °C.
- `CPU_THROTTLE_TEMP_CRIT` (default=70): Critical temperature threshold in °C.

#### Web UI
- `POWER_SENSE_OFF_MS` (default=10000): How long `POWER_SENSE_PIN` (GPIO4) must stay continuously LOW before the unit plays the goodbye screen and deep-sleeps (500–120000 ms). Any HIGH restarts the window, so ignition bounce and supply dips cannot stall the GPS task or sleep the dash (issue #26). Only used when `ENABLE_POWER_SENSE` is on. The Web UI row (**Sleep After Power Loss**) is shown and edited in **seconds** (0.5–120, in 0.5 s steps) and converted on save; NVS, config backups and the firmware keep milliseconds (issue #57).
- `ADV_MODE` (default=false): Global “Advanced Mode” toggle in the Web UI. When enabled, advanced and technical settings (CPU, GPS, Polling Rates, technical display options, advanced WiFi, and sensor-calibration internals) are shown as normal rows in their groups; when disabled they are hidden.

#### Display & Visual Design
- `DISPLAY_ROTATION` (default=3): Screen rotation (0, 1, 2, 3).
- `BACKLIGHT_BRIGHTNESS` (default=100): Backlight duty cycle (**0–100%**, clamped on load/save). The percent is turned into the 8-bit LEDC duty in one place (`backlightDuty()` / `applyBacklight()` in `src/main.cpp`), so no path — WebUI slider, night mode, boot splash, sleep/wake fade or auto-brightness — can put an out-of-range duty on the panel (issue #20).
- `NIGHT_BACKLIGHT` (default=29): Night-mode backlight duty cycle (0–100%), applied while night mode is active.
- `ENABLE_ANTIALIASING` (default=true): Anti-aliased line rendering toggle.
- `AA_SHARPNESS` (default=1.0): Anti-aliasing gamma correction factor.
- `GHOST_COLOR_STR` (default="#212021"): Hex color code for inactive 7-segment digit background.
- `COLOR_TEMP_NORM` (default=`#00ff00`), `COLOR_TEMP_WARN` (default=`#ffff00`), `COLOR_TEMP_CRIT` (default=`#ff0000`): the three colors of the engine temperature sidebar ramp, one per color fade point below.
- `TEMP_BAR_MIN` / `TEMP_BAR_MAX` (default=10 / 110): the two ends of the engine-temp sidebar bar in °C. **Scale only** — since the three-fade-point ramp they carry no color; what sits below the first fade point and above the last one is flat (issue #46 follow-up).
- `TEMP_WARN_LOW` (default=20): **color fade point 1** — °C where the bar leaves flat `COLOR_TEMP_NORM` and starts fading toward `COLOR_TEMP_WARN`. Below it the cold color is held (this is the Web UI row *Color fade point 1*). The width of this first band is `TEMP_WARN_YEL - TEMP_WARN_LOW`, which is the knob for a short or long cold hop.
- `TEMP_WARN_YEL` (default=45): **color fade point 2** — °C where the ramp reaches `COLOR_TEMP_WARN`; the `COLOR_TEMP_WARN`→`COLOR_TEMP_CRIT` fade starts there.
- `TEMP_WARN_RED` (default=90): **color fade point 3** — °C where the ramp reaches `COLOR_TEMP_CRIT`. **Above it the bar stays flat `COLOR_TEMP_CRIT`** all the way to `TEMP_BAR_MAX`; there is no fourth stop and `TEMP_BAR_MAX` no longer turns the bar red. Kept ordered `TEMP_BAR_MIN <= TEMP_WARN_LOW <= TEMP_WARN_YEL <= TEMP_WARN_RED <= TEMP_BAR_MAX`; equal neighbours collapse a band to a hard switch. The three stops are blended in RGB565 (`rampColor3()` over `blendColorLinear()`), so a yellow→red band walks through orange on its own, while a cyan low stop blended to amber goes through a muddy green that is in neither endpoint — which is why the shipped defaults stay on the green→yellow→red arc (issue #46). The dead `TEMP_WARN_GRN` marker removed in issue #29 is what `TEMP_WARN_LOW` replaces, this time stored in NVS, present in backups and editable in the Web UI.
- `COLOR_FUEL_NORM`, `COLOR_FUEL_WARN`, `COLOR_FUEL_CRIT`: Hex color strings for fuel status bar — the same three-stop model, mirrored: `COLOR_FUEL_NORM` at 100%, fades down through `FUEL_WARN_YEL` (Web UI *Color fade point 1*) and `FUEL_WARN_RED` (*Color fade point 2*), flat `COLOR_FUEL_CRIT` below the last one. Its drawing code (`src/ui.cpp`) is unchanged.

#### Sensors & Vehicle Calibration
- `WHEEL_CIRCUMFERENCE_MM` (default=1650.0): Tire rolling circumference in millimeters.
- `FUEL_FILTER_ALPHA` (default=0.08): EMA filter coefficient applied to the raw fuel ADC code.
- `FUEL_INPUT_ENABLED` (default=false): Turns the resistive fuel sender input on. Leave it off until a sender is actually wired to GPIO32 — with no sender the pin floats and the gauge reports "no input" and stays at 0 (issue #18).
- `FUEL_OHM_EMPTY` / `FUEL_OHM_FULL` (defaults=10.0 / 180.0): Sender resistance at empty and full, in ohms. Any standard works — 10–180 Ω (SAE), 240–33 Ω (European/VDO), 0–90 Ω (GM). Used to size the excitation resistor, define the fault band and pre-fill the calibration ramp.
- `FUEL_EXC_RES_OHM` (default=220): Resistor from 3V3 to GPIO32 that the sender forms a divider against. The Web UI suggests the best E12 value for the entered range (15 mA sender current budget, top of span below 2.6 V).
- `FUEL_ADC_VREF` (default=3.30): ADC reference / actual rail voltage in volts, used to turn the code into a divider voltage. It is no longer a Web UI field — the divider hangs off the 3.3 V rail and typing a different value only corrupted the excitation-resistor suggestion (issue #55). The parameter keeps its NVS key and its slot in config backups, so an existing backup still restores; a rail measured to be off should be corrected in the wiring, not here.
- `FUEL_OVERSAMPLE` (default=16): ADC conversions averaged into one sample (1–64). The ESP32 converter only delivers ~9–10 usable bits; oversampling is what buys the resolution back for a sender whose useful span can be a few hundred codes.
- `FUEL_TOUCH_POINTS` (default=8): Number of valid entries in the fuel calibration table (`fuelCalOhms`): index 0 = empty, index `N-1` = full, so the number of tank slots is one per litre for the shipped 1 L-per-step default. Changing this regenerates the table as a linear ramp between `FUEL_OHM_EMPTY` and `FUEL_OHM_FULL`.
- `TRIP_RESET_HOLD_MS` (default=1500): How long the physical trip-reset button on GPIO25 must be held to zero the trip stats (200–10000 ms). Shorter holds are ignored so a knock on the dash cannot wipe a trip. Refuelling no longer resets anything by itself (issue #17).
- `BATTERY_SCALE` (default=5.7): Battery divider ratio `(R1+R2)/R2`. Leave at `5.7` for the stock wiring; set to `4.7` for a 4.7 kΩ / 1 kΩ divider.
- `BATTERY_OFFSET` (default=0.2): Fixed voltage offset added to the divided battery reading.
- `NTC_R_BALANCE` (default=10000.0): Balance resistor value in ohms for NTC divider.
- `NTC_R25` (default=10000.0): Thermistor resistance at 25 °C (R25) in ohms.
- `NTC_BETA` (default=3950.0): Thermistor Beta coefficient.
- `NTC_TEMP_OFFSET` (default=0.0): Fixed temperature offset (°C) added to the Steinhart result.
- `GPS_BAUD` (default=115200): UART baud rate for the GNSS module. On boot the ESP listens passively across the common baud rates and stores the first rate at which the module's own traffic is seen. The module is **never** configured or reset by the firmware — no UBX command is ever transmitted; use u-center2 to change the module itself.
- `MIN_SATELLITES` (default=5): Minimum GPS satellite lock requirement.
- `OPTIMAL_SATELLITES` (default=8): Satellite count threshold for full GPS speed reliance.
- `MAX_SPEED_DELTA_KMH` (default=5.0): Maximum allowable difference between GPS and Hall speed before falling back.
- `SPEED_SOURCE_MODE` (default=2): Speed source — `0`=Hall only, `1`=GPS only, `2`=Sensor Fusion.
- `HALL_MEDIAN_SAMPLES` (default=3): Speed window size W (accepted pulses averaged); 1 = raw single interval.
- `HALL_PERIOD_GUARD` (default=8): Reject an interval longer than N× the last accepted one (the lower bound is fixed at 1/2 by Layer 2); `1` = off.
- `HALL_PULSE_MIN_US` (default=150): Layer 1 pulse-width qualification window in microseconds — a pulse whose measured `rise − fall` width is below this is dropped as EMI. Clamped to 10…1000 µs. Raise it when ignition EMI gets through; a genuine magnet pass is hundreds of µs wide, so 150 µs costs nothing. Measured from the stamped edges since 1.3.x (issue #30) — it no longer costs interrupt time.
- `ACCEL_MAX_TIME` (default=30.0): Acceleration timer maximum duration in seconds before auto-finish.

#### Weather Widget (Open-Meteo)
- `SHOW_ELEMENT_WEATHER` (default=true): Toggle the weather widget on/off.
- `WEATHER_CITY` (default=""): City label shown in the widget (GPS-geocoded when empty).
- `WEATHER_LAT` (default=0.0) and `WEATHER_LON` (default=0.0): Fallback coordinates for the Open-Meteo forecast request. While the unit has a GPS fix it uses the **live position** instead and these two are ignored; they are what the widget uses when there is no fix (no antenna, parked underground, GNSS off). With no fix **and** no coordinates set, no weather request is made at all. `WEATHER_CITY` is only the label, never the source of the coordinates.
- `WEATHER_REFRESH_MIN` (default=15): Refresh interval in minutes.
- `WEATHER_LOCALE` (default="it"): ISO locale code for the **city name** — the language the widget spells it in. With a live GPS fix the reverse-geocode (BigDataCloud) returns the name in this language. With no fix, the typed `WEATHER_CITY` is resolved on Open-Meteo's geocoding service and re-spelled in this language when that place has a name in it (`Milan` → `Mailand` for `de`, `München` → `Monachium` for `pl`); a name the service does not know (`Casa di NONNA`) or a match more than 150 km from the configured position is displayed exactly as typed, and the lookup is cached per name+locale so it costs one request per change, not per refresh. The service matches names *in the requested language*, so an exonym it doesn't index in that language (typing `Milano` while set to `de`) leaves the label untouched rather than swapping in a same-named town. Localization also needs coordinates to anchor on: with no fix and no `WEATHER_LAT`/`WEATHER_LON`, the typed name is shown as written. The localized spelling never overwrites the stored `WEATHER_CITY`. Only the Latin-script codes (`it en fr de es pt nl pl tr`) are localized on the panel — the Conthrax font subset has no verified glyphs for Cyrillic/Greek/CJK/RTL, so those keep the typed spelling (the WebUI has no such limit). The forecast itself is not translated. Saving a new value re-fetches the weather straight away, so the name changes without a reboot.
- `WEATHER_WIDTH` (default=480) and `WEATHER_HEIGHT` (default=28): Weather card size in pixels — width 160–480, height 20–120, set with the **Widget Size** sliders under *UI Layout → Weather Widget*. The card is anchored on its **centre**, so `OFFSET_WEATHER_X/Y` stay the point the card grows out from and a resized card does not slide sideways or down. The shipped defaults are the size the widget was before this was a setting, so a unit that never touches the sliders gets exactly the picture it had. The stat icons stay 16 px at any height (only `Conthrax_SemiBold_16px` and `28px` are compiled in), and the text stays 16 px: a taller card gives the rows more breathing room rather than bigger glyphs. **Rows:** the card keeps everything on one line whenever it fits, which is why the default 480×28 looks exactly as it always did. When a narrow card cannot hold the stats beside the city name it wraps them onto extra rows instead of dropping them, and each extra row costs about 20 px of height: a card at least ~40 px tall can use a second row, ~60 px a third. With a short city name and typical values, 240×48 shows city + temp + humidity on the first line and wind + sunset on the second, 160 px width needs ~60 px of height for all four stats, and a 160×20 card only has room for city + temp + humidity. Sunset is the group dropped first and wind second, and only when there is no row left to put them on; the exact cut depends on the city name and the current values, which are measured at draw time.

#### Time, Date & Daylight Saving
- `NTP_ENABLED` (default=true): Sync the system clock from NTP once the WiFi station is up. `configTime()` is armed and then polled **once per web-loop iteration** over a 5 s window — the old `delay(500)` retry loop ran inside the web task and left the config page and API unreachable for up to 5 s after every Wi-Fi join (issue #43). A missed sync is logged; a GPS fix or `POST /api/time` can still set the clock.
- `NTP_SERVER` (default="pool.ntp.org"): NTP host used for that sync.
- `TZ_OFFSET_HOURS` (default=1): Zone offset in whole hours — **the standard (winter) offset**, range −14…14. With DST on, this is the offset the clock uses outside the DST period; the rule below adds the extra hour. New York is `-5`, Paris is `+1`, Athens is `+2`.
- `TZ_DST_ENABLED` (default=true): Master switch for daylight saving. When off the clock keeps `TZ_OFFSET_HOURS` all year.
- `TZ_DST_RULE` (default=1): Which calendar `TZ_DST_ENABLED` applies (issue #22). `0` = none, `1` = **EU/EEA** (last Sunday of March and October, both at 01:00 UTC), `2` = **US/Canada** (second Sunday of March, first Sunday of November, both at 02:00 local wall clock — converted to UTC through `TZ_OFFSET_HOURS`, so a GMT−6 zone springs forward at 08:00 UTC and a GMT−5 zone at 07:00 UTC). The rules are integer arithmetic on the UTC date (no zone database); `scripts/verify_dst_rules.py` checks them against the published 2024–2026 transition instants. Before this parameter the DST half was hard-wired to the EU calendar, so a US zone was wrong for roughly three weeks a year.
#### WiFi & Cloud OTA
- `AP_PASSWORD` (default="12345678"): Password of the `Dashboard_Config` SoftAP (the configuration portal). Set in the WebUI (System & General → Wifi → Device Config AP). Must be **empty** (open network, not recommended) or **8–63 characters**: the Wi-Fi stack rejects 1–7 character passphrases, so a shorter value is refused at load/save time and the shipped default is restored instead (logged as `Config: AP_PASSWORD too short`). The WebUI warns while the default password is still in use.
- **Not parameters any more:** the search policy is fixed to *search forever* and TX power is fixed at `WIFI_POWER_19_5dBm` (19.5 dBm — the maximum the classic ESP32 accepts). `WIFI_RETRY_MODE`, `WIFI_RETRY_SECONDS` and `WIFI_TX_POWER_DBM` are gone from the parameter table, the WebUI and the backup template; a backup that still carries the old `WIFI_RETRY_M` / `WIFI_RETRY_S` / `WIFI_TXP` keys restores without them.
- `WIFI_ATTEMPT_SECONDS` (default=12, range 5–60): How long one network gets per try — the window covers the driver’s scan plus association, 4-way handshake and DHCP. A dead network is dropped earlier as soon as the driver reports its `STA_DISCONNECTED` reason (`NO_AP_FOUND`, wrong password, auth timeout), so this window only decides how long a *silent* network (in range but not answering, or a stalled DHCP lease) is waited for before the next slot is tried.
- `OTA_PULL_ENABLED` (default=false): Toggle automatic cloud pull (checks once per boot while enabled).
- `OTA_PULL_URL` (default=""): HTTPS URL of the update **manifest** — either JSON with `version` + `firmware_url`, or the GitHub `releases/latest` API URL (first `.bin` asset is used). The matching signature is fetched from `<firmware_url>.sig`.
- `VERSION_OVERRIDE` (default=""): Optional version **label**. When set, the unit reports this string instead of its compiled-in build version (`FW_VERSION` in `src/config.cpp`) — for display and as the reference version of the cloud OTA check, which is how you test an update pull against an arbitrary version. It never changes the firmware image, and nothing fetched from the network ever writes it (the previous behaviour of storing the manifest's version is why a unit could report a version it never ran). The real build version is always exposed read-only as `build_version` (`GET /api/config`) and shown in the WebUI (System → Firmware Update). NVS key `VER_OVR`.

#### Ambient Light (Auto-Brightness)
- `LIGHT_SENSOR_DARK_VAL`: Dark-reference ambient light value (calibrated via `/api/ambient/cal-dark`).
- `LIGHT_SENSOR_BRIGHT_VAL`: Bright-reference ambient light value (calibrated via `/api/ambient/cal-bright`).

#### Digit Boundaries (Configurable 7-Segment Formatting)
- `SPEED_DIGITS`, `SAT_DIGITS`, `TMR_INT_DIGITS`, `TMR_DEC_DIGITS`, `BAT_INT_DIGITS`, `BAT_DEC_DIGITS`, `INST_INT_DIGITS`, `INST_DEC_DIGITS`, `AVG_INT_DIGITS`, `AVG_DEC_DIGITS`, `AVG_SPEED_INT_DIGITS`, `AVG_SPEED_DEC_DIGITS`, `MAX_SPEED_INT_DIGITS`, `MAX_SPEED_DEC_DIGITS`, `FUEL_INT_DIGITS`, `FUEL_DEC_DIGITS`, `ODO_INT_DIGITS`, `ODO_DEC_DIGITS`: Configurable integer and decimal digit limits for all UI numerical readouts. These values size fixed 16-slot cell arrays in the display renderer, so they are range-checked on every load and save (issue #6): integer counts `1..14` (1-4 for `SPEED_DIGITS`, 1-3 for `SAT_DIGITS`), decimal counts `0..4`, and per readout `int + dec + 1 <= 16` (+1 is the decimal-point slot). Out-of-range values are clamped on load (boot, `POST /api/config`, config restore) and logged; the renderer keeps a hard bounds guard as a second line of defence. A readout also caps its *value* to what its configured digits can print (e.g. `FUEL_INT_DIGITS=1` + `FUEL_DEC_DIGITS=1` shows at most `9.5`; raise the int count to `2` in the WebUI — "Fuel & Battery" card → Fuel LTRS → Integer Digits — for two-digit litres), so a value with more digits than the cells never draws outside its cell array (issue #7). `SAT_DIGITS` (1–3) sizes the satellite readout the same way since issue #41: the count is capped to what N digits can print and the erase box is measured from N × `'8'` instead of a hardcoded two-digit string — before that the parameter was stored, exported, adjustable in the WebUI and documented, but no code ever read it. Separately, every digit loop resolves its character through `digitIndex()` in `src/ui.cpp` before touching the per-glyph metric tables (`digitWidth[10]`, `ds15_digitXOff[10]`, …): a character outside `'0'..'9'` returns `-1`, the cell is skipped and keeps whatever the ghost/erase pass already painted, instead of indexing a 10-entry table with `-3` (issue #31).

#### UI Layout Offset Coordinates
- `BIG_CENTER_X`, `BIG_CENTER_Y`: Screen anchor origin point.
- `OFFSET_BIG_TIME_X/Y`, `OFFSET_BIG_DATE_X/Y`, `OFFSET_BIG_SPEED_NUM_X/Y`, `OFFSET_BIG_SPEED_UNIT_X/Y`, `OFFSET_BIG_ODO_X/Y`, `OFFSET_BIG_SAT_X/Y`, `OFFSET_BIG_TMR_X/Y`, `OFFSET_BIG_BAT_X/Y`, `OFFSET_INST_KML_X/Y`, `OFFSET_AVG_KML_X/Y`, `OFFSET_AVG_SPEED_X/Y`, `OFFSET_MAX_SPEED_X/Y`, `OFFSET_FUEL_LTRS_X/Y`, `SIDEBAR_LEFT_X/Y`, `SIDEBAR_RIGHT_X/Y`: Fine-grained pixel coordinate offsets for every UI component.

---

## Codebase Architecture & File Map

```
Dashboard++ for ESP32/
├── platformio.ini         # PlatformIO project configuration & dependencies
├── partitions.csv         # Custom flash partition table (OTA + LittleFS)
├── data/
│   └── Fonts/             # VLW font sources (compiled to PROGMEM by scripts/vlw_to_header.py)
│       ├── DS-DIGIT_120px.vlw         # 120px 7-segment font (speed sprite)
│       ├── DS-DIGIT_28px.vlw          # 28px 7-segment font (time/odo/telemetry)
│       ├── Conthrax_SemiBold_28px.vlw # 28px header font
│       ├── Conthrax_SemiBold_16px.vlw # 16px label font
│       └── Conthrax_SemiBold_10px.vlw # 10px micro label font
├── scripts/
│   ├── gzip_webui.py      # Pre-gzips webui.html -> webui_html_gz.h (~93 KB raw -> ~20 KB)
│   ├── vlw_to_header.py   # Compiles .vlw font files into PROGMEM C headers
│   └── preview_icon.py    # Generates + geometry-checks the Android icon layers (android/app/src/main/res/drawable/)
├── include/
│   ├── Conthrax_SemiBold7pt7b.h  # GFXfont fallback (Small badge size)
│   ├── Conthrax_SemiBold4pt7b.h  # GFXfont fallback (Micro label size)
│   ├── DS_DIGIT_120px_vlw.h      # 120px 7-segment VLW font (PROGMEM)
│   ├── DS_DIGIT_28px_vlw.h       # 28px 7-segment VLW font (PROGMEM)
│   ├── Conthrax_SemiBold_28px_vlw.h  # 28px VLW font (PROGMEM)
│   ├── Conthrax_SemiBold_16px_vlw.h  # 16px VLW font (PROGMEM)
│   └── Conthrax_SemiBold_10px_vlw.h  # 10px VLW font (PROGMEM)
├── lib/
│   ├── ArduinoJson/       # Optimized embedded JSON parser/serializer library
│   └── TinyGPSPlus/       # NMEA 0183 GPS stream parser library
└── src/
    ├── dashboard.h        # Central global header, structure definitions, API declarations
    ├── main.cpp           # System setup(), dual FreeRTOS task spawns, main display loop
    ├── config.cpp         # One CFG_TABLE row per NVS parameter (global, keys, default, band); load/serialize/restore
    ├── gfx.cpp            # LovyanGFX display device class, PROGMEM VLW font loader, AA primitives, icons
    ├── sensors.cpp        # Core 0 GPS task (bulk UART drain, TinyGPS++/UBX parser, speed fusion, odo, time-sync) + Core 1 sensor task (Hall ISR, ADC sensors, snapshot)
    ├── ui.cpp             # Dirty-rendering dashboard visual layout engine
    ├── web.cpp            # SoftAP/STA WiFi manager, REST API handlers, cloud OTA pull, embedded Web UI
    └── webui.html         # Single-page Web UI source (gzipped at build time by scripts/gzip_webui.py)
```

---

## Build, Installation & Flashing Guide

### Prerequisites
1. Install [PlatformIO Core](https://platformio.org/install/cli) or VS Code with the PlatformIO extension.
2. Install Python 3.8+ and USB-to-UART bridge drivers (CP210x or CH340).

### Partition Table
The project uses a custom `partitions.csv` with:
- An **80 KB NVS partition** (`0x14000`, 20 pages) — 4× the 20 KB shipped until 1.4.0, see the changelog entry on NVS exhaustion
- Two OTA app slots (0x1D0000 each)
- A 256 KB LittleFS partition (0x40000), retained only for `/api/health` byte reporting (fonts are now PROGMEM)

Layout (4 MB flash, ends at exactly `0x400000`):

| Partition | Offset | Size |
|---|---|---|
| `nvs` | `0x9000` | `0x14000` (80 KB) |
| `otadata` | `0x1D000` | `0x2000` |
| `app0` | `0x20000` | `0x1D0000` |
| `app1` | `0x1F0000` | `0x1D0000` |
| `spiffs` | `0x3C0000` | `0x40000` (256 KB) |

> [!WARNING]
> A partition-table change is **not** delivered by an OTA update — OTA replaces the app slot, never the table. A unit that updates over the air keeps whatever table it was last flashed with, and the boot log line `NVS 'nvs' <bytes> bytes: …` is how you tell which one it is. Moving a board onto the new table needs a wired re-flash (`pio run -t erase` then `pio run -t upload`), and **the erase wipes NVS**: WiFi credentials, odometer and calibration have to be entered again.

#### Settings storage budget

Web UI → Performance panel → **Memory & Storage** shows `Settings storage (NVS …): 420 of 2520 entries used, 1974 available`, served by `/api/health`. The figures are entry **slots**, not bytes, because slots are what NVS actually runs out of — a partition can report hundreds of free slots and still refuse a write, since its tidier needs one spare page to move live data into. `available` already subtracts that reserve, so it is the number to watch; it turns amber below 15 % of the total and red below 3 %, where saves start failing. ESP-IDF garbage-collects NVS automatically inside its own write path — there is no public compaction call in arduino-esp32 3.3.x — so this readout is deliberately observation only.

### Compiling & Flashing via USB

```bash
# Clone the repository
git clone https://github.com/alefinot/Dashboard-for-ESP32.git
cd Dashboard-for-ESP32

# Compile project source code
platformio run

# Flash firmware binary to ESP32 over serial USB
platformio run --target upload

# Open serial device monitor (115200 baud)
platformio device monitor
```

> [!NOTE]
> Fonts are compiled into flash as PROGMEM arrays at build time (`scripts/vlw_to_header.py`), so no `uploadfs` step is needed for text. The LittleFS partition remains in `partitions.csv` (used only for `/api/health` byte reporting).

### Over-The-Air (OTA) Updates

#### Via PlatformIO CLI
Ensure your host machine is connected to the `Dashboard_Config` WiFi network or local network:

```bash
platformio run -t upload --upload-port 192.168.4.1
```

#### Via Web Management Portal
1. Open a browser and navigate to `http://192.168.4.1` (or your assigned STA IP).
2. Open the **System Actions** section.
3. Click **Choose File**, select the `.pio/build/esp32dev/firmware.bin` file, and click **Upload**.

The upload path is a local developer path: it is **not** signature-checked, but it
is bounded by the real OTA partition size, and an upload whose byte count is
inconsistent or whose ESP image header does not look like firmware (magic `0xE9`,
plausible segment count, at least 4 KB) is discarded instead of activated.

#### Cloud OTA Pull & Firmware Signing

The cloud pull (Web UI → **System & Modes** → *Cloud OTA Pull*) reads a small JSON
manifest from `OTA_PULL_URL`, then downloads and flashes the image it points at:

```json
{ "version": "1.4.1",
  "firmware_url": "https://github.com/alefinot/Dashboard-for-ESP32/releases/download/v1.4.1/firmware.bin" }
```

`OTA_PULL_URL` may also point straight at the GitHub API
(`https://api.github.com/repos/alefinot/Dashboard-for-ESP32/releases/latest`), in
which case the first `.bin` asset of that release is used — keep **one** `.bin`
asset per release so the wrong file can never be picked.

Every pulled image is verified before it is allowed to boot:

| Guard | What happens when it fails |
|---|---|
| TLS certificate checked against the CA bundle compiled into the core | connection refused, mbedTLS reason logged |
| Manifest version differs from the compiled-in `FW_VERSION` | "already up-to-date", nothing downloaded |
| Sibling asset `<firmware_url>.sig` exists and is readable | update refused (a missing signature is never a pass) |
| ECDSA P-256 / SHA-256 signature valid over `sha256(firmware.bin)` + version | slot discarded, no reboot, reason shown in the Web UI |
| Every byte hashed exactly once | byte-range resume is switched off while signing is enforced; the image restarts from byte 0 |

`Update.end(true)` — the call that makes the new slot bootable — runs **only
after** the signature verifies. The public key is compiled into the firmware
(`include/ota_pubkey.h`); a firmware image built without it refuses every pull.

**Signing a release (maintainer side)**

The private key never enters the repository (`keys/` is gitignored); only its
public half is committed, generated into `include/ota_pubkey.h` (generated file —
regenerate with the script, never hand-edit):

```bash
python scripts/ota_sign.py keygen                                  # once, on the signing machine
python scripts/ota_sign.py pubkey                                  # refresh include/ota_pubkey.h
python scripts/ota_sign.py sign   1.4.1 .pio/build/esp32dev/firmware.bin
python scripts/ota_sign.py verify 1.4.1 .pio/build/esp32dev/firmware.bin
```

`sign` writes `firmware.bin.sig` next to the binary — a DER ECDSA P-256 signature
over `sha256(firmware.bin) || 0x0A || version`. Upload it as a **sibling release
asset**; a release without the `.sig` will not install on any device. The signed
version is the plain number (`1.4.1`) — the release tag is `v1.4.1`, and a `v`
prefix in a manifest version is stripped before the version compare.

Keep `keys/ota_sign_key.pem` backed up offline and private: lose it and no future
signed release can be built; leak it and anyone can ship firmware to every device.

> [!NOTE]
> **Bench builds only.** Adding `-DOTA_ALLOW_UNSIGNED` to `platformio.ini` builds
> the pull path without the signature check (the Web UI logs a warning on every
> pull). Never publish a release built with that flag. USB serial flashing and
> ArduinoOTA (`espota`) stay unsigned by design — they are local developer paths.

---

## Simulation & Demo Mode

Dashboard++ includes an integrated simulation engine for bench testing UI rendering without requiring connected physical hardware.

To enable Demo Mode:
1. Open the Web UI at `http://192.168.4.1`.
2. Expand the **System & Modes** section.
3. Enable **Demo Mode**.
4. Click **Save Settings** (or wait 2 seconds for autosave).

In Demo Mode:
- Speed oscillates synthetically between 10 km/h and 110 km/h using sinusoidal formulas.
- Engine temperature, fuel level, battery voltage, satellite count, instant/avg KM/L, and average speed simulate active riding telemetry.
- Speed source indicator badge automatically cycles between `HAL`, `GPS`, and `G+H` every 2 seconds.

---

## Changelog

### V1.4.2 — live readings that never skip a second (firmware + Web UI)

The settings page's live cells (ambient light, odometer, fuel ohms/state, coolant temp, battery volts) used to advance every 1 s on a good moment and every 2 s on a tired one. They now come from one request per second and cannot miss a tick.

**The mechanism** — the core's `WebServer` serves **one client at a time** (`WebServer.cpp`: "Supports only one simultaneous client"; `NetworkServer` listens with a backlog of 4; every reply is `Connection: close`, so each poll costs a fresh TCP handshake), and the web task calls `handleClient()` once per ~10 ms. The page was firing **four simultaneous fetches every 1000 ms** (`/api/ambient`, `/api/odo`, `/api/fuel`, `/api/sensors`). When a batch outlived the tick, the next batch met a full backlog and its sockets were refused — and every poller swallowed the failure with `.catch(() => {})`, so the symptom was "that cell didn't change", not an error. `scripts/verify_live_poll.py` re-creates those server constraints on the host and measures both patterns: at a 300 ms per-request cost the four-parallel pattern misses 11-14 of 12 ticks with the worst median interval at 1235-1399 ms (at 400 ms it is 2031 ms — the reported "every 2 seconds"), while the single-lane pattern is 0 missed ticks at exactly 1000 ms.

- **`GET /api/live`** — one atomic snapshot of all five live readings, allocation-free like `/api/health` (fixed `char[176]`, one `snprintf`, one `g_stateMutex` take). The four single-value endpoints stay registered and unchanged for other consumers.
- **One request lane in the page** — `laneFetch()` keeps at most one request in flight for every periodic read (live values, Performance Monitor, serial monitor) and aborts it at `LIVE_ABORT_MS = 900`, under the 1000 ms tick and far under the server's `HTTP_MAX_DATA_WAIT` = 5 s. A slow device loses that sample instead of stacking sockets on top of itself; returning to a foregrounded tab polls straight away instead of waiting for the next tick.
- **Both ends are measurable now** — `/api/perf` gained `web_serve_ms_last`, `web_serve_ms_max` and `web_slow_iters` from the web task's own loop, and the Performance Monitor gained a **Live Poll** row showing the browser round trip with `N ok / N missed` beside the device's serve time. Polls stopped being invisible, which is what made this bug last.
- `scripts/verify_live_poll.py` is the regression gate: `python scripts/verify_live_poll.py --serve-ms 300 --ticks 12` must stay green (lane clean, parallel demonstrably degraded), with `--shape-only` pinning the endpoint contract and the four legacy GETs still registered, `--counters-only` pinning the perf fields, and `--webui-only` pinning the page structure (one `setInterval(liveTick, 1000)`, no fan-out, no periodic read of the single-value endpoints).
- **Measured on the device too:** `python scripts/verify_live_poll.py --device http://<ESP_IP> --ticks 20 --load 2` runs both patterns against real hardware while two extra clients pull the 51 KB UI page (an idle dashboard on a bench hides this bug — the old pattern is clean until something else is served). On a 1.4.1 board: old four-fetch pattern **7 missed ticks and 2 refused requests of 20**, fixed lane **0 and 0** with a 1016 ms median interval, while the firmware's own `web_serve_ms_max` stayed at 212 ms. Driven from a real browser, the page counted **21 ok / 0 missed** in 20 s at a 123 ms round trip, with the five cells changing on the same 1000 ms beat.

---

#### Android app — the launcher icon redrawn around one bold dial

Nothing in the firmware: the app's icon, the script that generates it, and a debug APK with `versionCode` 6 → 7 (1e85ea5).

**The mark**
- **One bold dial, not a decorated gauge** — a 260° arc in a single 8.5 dp weight, open at the bottom-left where a real speedo's zero sits. The old mark's ticks, inner rim and hairline needle are gone; at launcher size they were noise (1e85ea5).
- **The redline is part of the dial, not a patch on it** — the last 26° of the same arc is painted `hud_red` and joins the cyan at one shared endpoint, so the two strokes meet with no seam and no overlap (1e85ea5).
- **The needle is held by the hub** — a solid amber wedge with parallel 5.5 dp shoulders and a tail inside the hub circle, pivot at the dial centre, tip at r 20 dp against a dial at r 25.5 dp. The hub is a 7 dp amber disc with a 2.5 dp dark pivot hole (1e85ea5).
- **The mark sits 2.5 dp low on purpose** — an arc open at the bottom carries all its ink high, so a canvas-centred dial reads high inside the launcher mask; the gauge centre is at y 56.5 of 108 and the ink lands 4.1 dp below centre (1e85ea5).
- **The background is no longer flat** — `@drawable/ic_launcher_background` lifts `hud_bg` with a radial cyan glow (`hud_icon_glow` → `hud_icon_mid` → `hud_bg`) behind the dial, so the black tile has depth instead of looking like a dead screen (1e85ea5).
- **Themed icons still work** — `ic_launcher_monochrome.xml` carries the same path data in one colour, and `ic_splash.xml` (the in-app splash glyph) is the same mark scaled 1.55×, pivoting on the gauge centre rather than the canvas centre (1e85ea5).

**Why the old mark could not be saved** — measured, not judged: its 1.5–2.5 dp strokes are under one physical pixel on a 48 dp launcher tile, so at 28 px the ticks smear into a fringe and the needle disappears entirely. A gauge that only reads at 512 px is a poster, not an icon.

**How the design is kept honest** — `scripts/preview_icon.py` is now the single source of the icon: one spec entry generates all four vectors (`--write`), and the geometry is checked (`--check`) rather than eyeballed — nothing outside the 66 dp guaranteed-visible circle, 1.25 dp of air inside it, no stroke thinner than 3 dp, the air above and below the mark within a factor of two, one dominant weight and one secondary, the needle symmetric about its own axis with its tail inside the hub, and the redline meeting the dial at a shared endpoint. `--xml FILE` fails when a shipped vector drifts from the design, and `--write` refuses to emit a design that fails its own check. The four `drawable/ic_launcher_*.xml` / `ic_splash.xml` files are generated output — change the spec in the script, never the XML.

### V1.4.1 — The settings page on a phone: option lists that really open in the Android WebView

Everything in this release is on the config page and in the Android app: how settings are grouped, read and saved, and the dropdown lists that were invisible in the app on some phones. No firmware behaviour, no pins, no endpoints, no NVS parameters changed.

**Config dropdowns (issues #50, #58, #59, #60)**
- **The native `<select>` popup is gone** — every option list on the settings page is drawn by the page itself (`#sel-panel`), so the list keeps the dashboard's look instead of the phone's system picker, and the same markup behaves the same in a desktop browser (6c65d30, e86d1cc).
- **A list opens on its control, at its width** — the panel is anchored to the value box it belongs to and sized to it, flips above when there is no room below, and is clamped so it always ends up inside the visible area (fee85a0, e417ffc). Long option labels no longer push a settings card wider than the page (#60 follow-up).
- **Touch scrolling works and a dismissed list does not eat the next tap (#58, #59)** — the list scrolls with a finger, the panel closes on an outside tap, and the ghost click that used to land on whatever sat under the closing panel is swallowed (5571533). Picking an option fires the `input` event, so the choice reaches the autosave instead of sitting unapplied until the next field was touched (a22e08d).
- **Why the lists never appeared in the app (#60)** — measured on the reporting phone (Xiaomi, WebView 153) with the page laid out correctly at 380 × 801 CSS px: `1svh`, `1vh`, `1lvh`, `1dvh` and `1vmin` **all resolve to 0 px**, while `innerHeight` reports 801 and `100vw` reports 380. The panel's `max-height: min(280px, 60svh)` therefore computed to **0 px** and the box measured 120 × 2 px — a strip nobody could see, with the three options still in the DOM, which is why a blind tap on empty space still changed the value. Nothing else about the page was wrong, which is why it looked like an overlay or font problem for two rounds.
- **So the list is sized in px, from numbers the engine reports** — `--panel-max` is a plain `280px`, and `positionSelPanel()` writes `max-height`, `width`, `top` and `left` in px from `visualViewport`/`innerHeight`, with floors (120 px minimum height, 120 px minimum width) so a viewport reported as 0 can never collapse the box. `body { min-height }` uses a `--vp-h` property written in px at boot and on resize, because `100vh` is 0 there too — the pull-to-refresh distance used the same broken unit. No height-based viewport unit remains anywhere the option list depends on.
- **The box is read back instead of trusted** — after anchoring, the panel's real `offsetHeight`/`getBoundingClientRect()` are checked; if it came back under 40 px or off-screen it switches to a centred sheet layout and is placed again. The failure mode stops being "tapping does nothing", which is what this bug was. `?dbg=1` on the config URL logs the panel geometry on every open (`window.__selDbg(tag)` on demand) — the missing piece in the two earlier blind attempts.
- **No frosted glass on the list** — `backdrop-filter: blur(12px)` over a 75 %-opaque panel is replaced by a solid background. It was the standing suspect for #60 (a blurred translucent overlay can render empty in this WebView class), it costs nothing to remove, and it is one failure mode fewer.

**Settings page readability**
- **Cards regrouped, prose trimmed** — the settings cards are re-grouped, paragraph text cut, and card titles, notes and buttons unified in one style (ca971e5, eb1e1b7). Scrollbars are themed to the dashboard palette instead of the browser default (094e9a8). The page polls telemetry at 1 Hz rather than per-panel timers, and the power-off countdown is shown in seconds (eb1e1b7).
- **Small consistency fixes** — `WEATHER_LOCALE` is stored as text and the `(default)` marker is dropped from the *Italiano* option, "Connected" is no longer forced to caps, the Wi-Fi badge and the hidden-network add row line up with the rest of the card (6c65d30, 3355abb, e417ffc, 68f5e2d).

**Android app**
- **The WebView honours the page's own viewport (#50)** — `useWideViewPort` is now enabled (WebView's default is off, unlike a browser), so the config page is laid out at the device width — 380 CSS px on the reporting phone — instead of a 980 px canvas scaled to fit. Body-level overlays such as the option list were anchored against that phantom geometry (b9e36e0).
- **One abandoned file picker no longer kills the next ones (#49)** — the OTA upload and backup-import inputs share a single chooser callback; an abandoned attempt now resolves the previous callback with an empty result instead of leaving it pending, which used to make Chromium refuse every later chooser on the page (b9e36e0).
- **New launcher icon** — a stylized speed gauge replaces the placeholder mark (1d22469). `versionCode` 5 → 6 for the shipped debug APK.

**Reverted, and therefore not in this release** — the VLW font loader rewrite (25d9ae1), the overlay font-fallback / weather-card-margin / battery-axis changes (ccd062a, reverted in ad6294a) and the first attempt at dropdown anchoring, scrolling and picking (reverted in 8fe7d83) are all out; the symptoms they were aimed at remain open, and #60 is now closed without them.

**Size and tooling** — `RAM 24.3 %` (79,564 B of 327,680 B), `Flash 91.8 %` (1,744,531 B of the 1,900,544 B OTA slot, ~156 KB headroom). Firmware `1.4.1` signed for the cloud pull (`firmware.bin.sig`, verified with `scripts/ota_sign.py`).

### V1.4.0 — Input validation sweep, NVS discipline, receive-only GNSS, marine fuel sender and a trip-reset button

The issue-sweep release: 35 reported defects closed since V1.3.9, plus three user-facing features. No pin changes.

**New features**
- **Marine resistive fuel sender (#18)** — the fuel input is no longer demo-only. GPIO32 (ADC1_CH4) reads a resistive tank sender through the calibration table; `FUEL_OHMS_MIN`/`FUEL_OHMS_MAX` describe the sender's empty/full resistance, the ADC is characterised once at boot (`Fuel: raw … at E/F ohms`) and refuel detection works outside simulation.
- **Trip-reset button on GPIO25 (#17)** — debounced active-low input with internal pull-up resets trip distance, trip time, average speed and session max. The automatic refuel trip-reset is gone: a trip is reset by the button or the Web UI only.
- **DST rule selector (#22)** — `DST_RULE` picks `EU`, `US` or `none`, so zones whose summer offset is not simply base+1 h stop drifting an hour twice a year. `TZ_OFFSET_HOURS` is documented as the winter/base offset and is now bounded (#35).

**Config input validation**
- **Every numeric parameter has a band (#21, #20, #13, #34, #35, #36)** — 131 parameters carry an accepted range checked on read, on write and after an NVS load; out-of-band input keeps the last-good value and logs it. Includes the panel SPI clock (#13 — a 0 or oversized value blanked the ILI9488), backlight clamping through one shared helper (#20), `setCpuFreqMHz()` return checking (#34), `TZ_OFFSET_HOURS` bounds that previously overflowed the local-time maths (#35), and `TARGET_FPS` bounds that also retire a dead branch (#36). `scripts/verify_config_ranges.py` fails when a parameter is missing from the table.
- **Digit counts really are boundaries (#6, #7, #41)** — counts are clamped to the cell arrays that draw them (14 cells max), values are capped to what N integer digits can print, and an over-wide string drops leading characters instead of indexing a cell array at `-1`. `SAT_DIGITS` (1–3) is wired to the satellite readout (#41): value capped, erase box measured from the configured width.
- **WebUI limits are generated, not hand-maintained** — `scripts/make_webui_limits.py` regenerates `FIRMWARE_LIMITS` from `config.cpp` so a web input can never accept a value the firmware misuses.

**Weather city language**
- **City name follows `WEATHER_LOCALE` with no GPS fix** — with the GNSS dark the typed `WEATHER_CITY` is looked up on Open-Meteo's geocoding service (`geocoding-api.open-meteo.com`, keyless, plain HTTP) and the widget shows that place's name in the configured language (`Milan` → **Mailand** in German, `München` → **Monachium** in Polish). Candidates more than 150 km from the configured position are discarded — an un-hinted `Milano` search first hits Milano, Texas, 8,694 km away — a name the service does not know is kept exactly as typed, the lookup needs coordinates to anchor on, and the answer is cached per name+locale, so it is one extra request per change rather than per refresh. `WEATHER_CITY` itself is never rewritten. Spellings the panel font cannot draw (non-Latin locales) keep the typed name, and localized names are now cut on a character boundary instead of through a multi-byte sequence (`copyFixed` is shared with `ui.cpp`).

**Concurrency and shared state**
- **GPS read through a snapshot, not cross-core TinyGPS++ (#9)** — display and odometer paths read the mutex-guarded `g_gpsFix` copy; the TinyGPS++ objects belong to `gpsTask` alone. A weather fetch used to steal the odometer's pending fix mid-ride.
- **Odometer reads locked as well as writes (#14)** — the 8-byte `totalDistanceKm` is copied under `odoMux`, so telemetry can no longer show a torn value.
- **Weather text under `g_stateMutex` (#8)** — the display task copies the fixed-size weather fields under the lock instead of racing the fetch task (the `String` members are gone too).
- **`POST /api/config` no longer reconfigures live from the web task (#10)** — bus and CPU changes raised by a save are applied by the display loop, which owns the panel.
- **Task creation checked (#25)** — a `sensorTask`/`gpsTask`/`webServerTask` that cannot start is logged and retried with a smaller footprint instead of the dashboard silently showing zeros.
- **NTP no longer blocks the web server (#43)** — the post-Wi-Fi wait that froze every endpoint for up to 5 s is now a non-blocking settle poll.

**GNSS**
- **The link is strictly receive-only** — `ubxSend()`, the recovery-command path and the boot reconfiguration are removed. Nothing is ever written to the GNSS UART; the module is left exactly as configured and the dashboard only parses what it receives (the #11/#26/#39 recovery machinery goes with it).
- **UBX parser cannot desync (#33)** — a zero-length payload frame advanced the state machine wrongly and cost frame sync until the next NMEA line; the parser now consumes exactly one frame. `scripts/verify_ubx_parser.py` replays the 11 malformed cases, including the two that hung the parser.
- **Fix validity read correctly (#12)** — NAV-PVT fix state comes from the fix-validity flag, not the time-validity bit.
- **Boot RESET capture bounded (#39)** — the pre-reset serial capture buffer can no longer saturate before the command arrives.

**Power and uptime**
- **Power-sense blips don't park the GPS task (#26)** — `POWER_SENSE` LOW is debounced, and a real power loss sleeps 10 s instead of halting forever.
- **Stacks measured and sized (#27)** — `gpsTask`'s 1 KB buffer inside its 4 KB stack plus the snapshot path came within ~100 bytes of overflow; high-water marks are reported (`TASKS: gps high-water … bytes`) and re-sized on a half stack.
- **Overlay redraw actually gated (#15)** — the GPS debug overlay compared values that could never match and repainted every 500 ms; caching restores the intended cadence.

**Sensors and rendering**
- **Hall ISR no longer busy-waits (#30)** — the 1 ms width-qualification loop ran with interrupts disabled on the core driving the display; edges are stamped in the ISR and width-filtered on the task.
- **Fuel gauge cannot freeze on a bad table (#19, #4)** — out-of-order (E > F) calibration rows are repaired on load, and a reading outside the table clamps instead of sticking at a stale value.
- **No-data fuel readout (#16)** — a trip with no driving shows `0`, not the placeholder `99.9 km/L`.
- **Temperature marker cleanup (#29)** — the green `TEMP_WARN_GRN` marker (never stored, exported or exposed) is removed; the gauge fades blue → amber → red across the two remaining thresholds.
- **Digit renderers validate their input (#31)** — every digit loop resolves its character through `digitIndex()` before touching the 10-entry per-glyph metric tables; a non-digit skips the cell instead of reading out of bounds.
- **Text bounds contract documented (#44)** — `getTextBounds()` is advance-based by definition (`x1` always 0, `y1 = -baseline`); the `- x1` terms in the layout code are a documented slot, not a live offset.

**WiFi connectivity**
- **The search really walks the saved networks** — since the arduino-esp32 3.3.12 / ESP-IDF 5.5.5 core migration (V1.3.6), `esp_wifi_set_config()` returns `ESP_ERR_WIFI_STATE` while a connect attempt is in flight (`esp_wifi.h`: "ESP_ERR_WIFI_STATE: WiFi still connecting when invoke esp_wifi_set_config"), and the core auto-reconnects on its own by default (`STAClass::_autoReconnect = true`, `WIFI_REASON_NO_AP_FOUND` counts as reconnectable) — so a failed SSID leaves an attempt armed on that SSID forever. Every `WiFi.begin()` for the next saved network was refused: the STA config never changed, `WiFi.status()` never reached `WL_DISCONNECTED`, and the unit stayed pinned to the first network it tried (typically the primary), never reaching `WIFI_SSID_1…4`; a lost link was never re-searched either. The search loop now owns reconnects (`WiFi.setAutoReconnect(false)` plus a `WiFi.onEvent` handler), waits for the driver to report an attempt over before installing the next SSID, gives up on a dead network as soon as its `STA_DISCONNECTED` reason arrives instead of waiting out the 5 s window, and always restarts from slot 0 — which since the network picker landed below is *the network that connected last*, not a hand-picked primary. Verified by build and code review; the ESP-IDF rule is confirmed against the 5.5.5 headers and espressif/esp-idf#17484.
- **The search never expires — and there is nothing left to configure** — `WIFI_RETRY_MODE` and `WIFI_RETRY_SECONDS` are removed as parameters (NVS keys, WebUI controls and backup-template entries all gone): a cycle through the saved networks that ends without a join is followed by the next cycle after a 2 s backoff, indefinitely, and `STA_GIVEUP` is only ever reached when *nothing* is configured to search for. The old “stop after one cycle / search for a fixed time” options were the reason a unit could sit offline for hours after its router rebooted. The heartbeat line gains `sta=<phase>/<net>/<reason>` and `STA link lost (reason=…)` names the driver’s `WIFI_REASON_*` code, so a unit that will not join is diagnosable without reproducing it.
- **TX power was being set 16× lower than the setting claimed — now fixed at the module maximum** — `WIFI_TX_POWER_DBM` (−1…20, default 20) was passed straight into the `wifi_power_t` enum: that enum is **0.25 dBm steps**, not dBm (`WIFI_POWER_5dBm = 20`, `WIFI_POWER_8_5dBm = 34`, `WIFI_POWER_19_5dBm = 78`), so “20 dBm” selected raw value 20 = **5 dBm**, and the log agreed with the setting instead of the radio. The unit has been transmitting at ~3 mW, which also weakens probe and ACK power — a direct candidate for the `WIFI_REASON_NO_AP_FOUND` results on networks that are plainly in range. `WiFi.setTxPower(WIFI_POWER_19_5dBm)` is now compiled in (raw 78: `esp_wifi_set_max_tx_power()` accepts 8–78 on the classic ESP32; ESP32-WROOM-32 datasheet Table 17 quotes 19.5 dBm typ for 802.11b, 18.0 dBm for HT20 MCS0 — the PHY backs the PA off by rate itself), logged truthfully as `WiFi TX power: 19.5 dBm (raw 78, module maximum)`, and the slider is gone.
- **Networks added after boot are found without a reboot** — the search list was built once when the web task started, so a second or third SSID saved through the Web UI stayed invisible to the search until the next reboot (the config globals are pointed at, so editing an *existing* slot did take effect — only the list length was frozen). The list is now rebuilt at every search-cycle boundary, and boot logs the credentials NVS actually returned: `WiFi credentials from NVS: [0]=Home/pw set [1]=Cafe/pw set [2]=(no SSID)/pw empty …`.
- **Wi-Fi setup is now the phone flow: scan, tap, type the password once** — the Network panel no longer has ten SSID/password boxes labelled Primary and Fallback 1–4; it has **Scan Networks**, a signal-strength list of what the radio can hear, and **Forget**. `GET/POST /api/wifi/scan` serve a static 30-entry scan cache (no per-request heap, AGENTS §14) that is refreshed on request and after a failed search cycle; `POST /api/wifi/join` and `POST /api/wifi/forget` write the same five `WIFI_SSID`/`WIFI_PWD`…`WIFI_S4`/`WIFI_P4` slots the firmware has always used, so nothing about storage or the Android consumer changed. A tap on a stored network reconnects with its stored passphrase instead of blanking it, and a fifth network when all slots are full returns `status:"full"` and makes the user name which one may go — credentials are never silently displaced. Hidden networks keep an explicit add-by-name row, since a scan cannot see them — and that SSID box now carries an explicit `type="text"`, because an `<input>` with no `type` attribute never matches the `input[type="text"]` rule and rendered unstyled next to the styled password box.
- **The network that worked is tried first** — when a join succeeds, that SSID/password pair is rotated to slot 0 in RAM and NVS (`WiFi: <ssid> is now the first network tried`), and a lost link restarts at slot 0. “Primary” is therefore whatever this vehicle can actually reach, decided by the device instead of by whoever filled the form last. Joins are a handful per day, so the rewrite stays inside the NVS wear rule (AGENTS §12), and pairs that already match are not rewritten.
- **Longer, better-targeted connect attempts** — a per-network window of `WIFI_ATTEMPT_SECONDS` (default 12 s, was a hard 5 s) now covers the driver scan, association, handshake *and* DHCP, which is what a cold scan plus a slow lease actually needs; the attempt is still abandoned early when the driver reports a definite reason. The channel from the last scan of that SSID (if younger than 30 s) is passed to `WiFi.begin()`, so the driver starts on the right channel instead of sweeping 1–13 first — roughly 1 s instead of ~4 s for a join. When a whole cycle fails, one log line names what the radio could see (`WiFi scan (12s ago): D-Link627F3B -48 dBm ch6 …`), which settles “is it out of range or is it the password?” without a repro.

**OTA and NVS robustness**
- **One NVS session, one lock (#32)** — an RAII `NvsSession` holds `prefsMux` across the whole `begin()/end()` pair at all 13 call sites; every failed write is counted and reported (`Config save: 3 parameter(s) failed to reach NVS … they will revert on reboot`), the ambient-calibration endpoints answer `saved-ram-only`, and a boot that cannot read NVS no longer seeds factory defaults over an unreadable namespace.
- **That write reporting was itself inverted, and is now right** — `Preferences::put*()` returns the number of bytes written (`0` on failure, `1` for numerics, `strlen(value)` for a string), not an `esp_err_t`, and the #32 helper compared that count against `ESP_OK`. A genuine failure (0) therefore read as success — the silent loss #32 was raised to stop — while every successful write logged a bogus failure whose "error name" was the value's length (`NVS: write of WIFI_S1 failed (0xc)` for a 12-character SSID). The helper now takes the byte count (with a separate overload for the `bool`-returning `clear()`/`remove()`, plus an empty-string-aware variant so clearing an SSID is not a false alarm), failures log once with the key name, and a save answers `nvsErrors: N` / `nvsFailedKeys` / `nvsAvailable` so the Web UI names the keys that did not stick instead of showing "Configuration saved successfully".
- **The factory-default seed no longer erases the stored SSIDs** — `FACTORY_DEFAULT_JSON` carried all five SSIDs as empty strings, so any boot that found `CFG_VER < 5` cleared every saved network name in RAM and NVS (passwords were already left out). The `CFG_VER` stamp was written unchecked, so one lost stamp repeated that wipe on every boot: credentials had to be retyped each session and looked unsaved. WiFi credentials are now excluded from the seed — matching a Factory Reset, which deliberately puts them back — and the stamp is checked and logged when it cannot be stored.
- **The NVS budget is visible in the Web UI, not only the log** — boot logs `NVS 'nvs' N bytes: N entries used, N available, N free, N total, N namespace(s)` (and again after a save that failed), plus `WiFi credentials from NVS: [0]=Home/pw set [1]=(no SSID) …`, and `/api/health` now carries `nvs_bytes` / `nvs_entries_used` / `nvs_entries_available` / `nvs_entries_total` so the Performance panel → Memory & Storage shows a permanent `Settings storage (NVS 80 KB): 420 of 2520 entries used, 1974 available` line (amber under 15 % available, red under 3 %). The numbers are entry slots rather than bytes because slots are what runs out, and the read is throttled to one page-walk per 5 s. ESP-IDF tidies NVS inside its own write path and arduino-esp32 3.3.x exposes no public compaction call, so this is deliberately observation only.
- **The real cause of the lost WiFi saves: the NVS partition was full** — with `nvs` at 20 KB (5 pages, one always reserved for garbage collection) a unit reported `NVS has 1 free entries`, and the two writes that could not fit were `WIFI_SSID`/`WIFI_PWD` — **slot 0, the primary network**, which is why it looked hardcoded while a secondary slot saved fine when room happened to be free. Two changes, one layout and one behavioural:
  - **`nvs` is now 80 KB** (20 pages) in `partitions.csv`, taken from LittleFS (320 → 256 KB), which has held nothing since fonts moved into the binary. Offsets shift, so this only reaches a board through a wired re-flash — and OTA-updated boards keep the old table until they get one.
  - **A save now writes only what changed.** Every `CFG_*` parameter, the WiFi passwords and the fuel ramp are read back first and skipped when the value already matches. The old behaviour rewrote all ~200 parameters on every autosave; re-storing a string at a different length strands its old 16-byte items, and those can only be erased once a whole page holds nothing live — with ~200 keys spread over four usable pages that never happened, so stale items grew until the partition was full. This is also the wear rule (AGENTS §12) applied to the save path rather than only the odometer.
- **The BOOT-hold recovery gesture could be fired by a PC, and it took the odometer with it** — the gesture watched GPIO0 for 8 continuous low seconds, but GPIO0 is driven by the USB-serial adapter's DTR line through the auto-reset transistor, so any host holding DTR asserted (a serial monitor left open across a boot is enough) wiped the configuration eight seconds after every power-on, silently, with nobody near the board. Two resets were reproduced on the bench before the cause was found, and the same capture with DTR de-asserted boots clean. It is now a two-stage gesture — hold 4 s, **release**, hold 4 s again, all inside the first 30 s — which a stuck-low line can never satisfy, and every abort path logs its reason (`Factory reset aborted: BOOT was never released …`). A factory reset also no longer clears the `dashboard` namespace: recovering from a forgotten config PIN is no reason to erase the vehicle's lifetime mileage, and unlike the settings, an odometer cannot be re-entered from memory. Applies to all three reset paths (BOOT gesture, serial `RESET`, `POST /api/reset`).
- **Progress bar cannot divide by zero (#38)** — a zero or negative total in `updateOTAProgress()` raised an integer-divide panic in the ArduinoOTA callback mid-update.
- **Boot provenance complete (#42)** — every `esp_reset_reason_t` maps to a label, unmapped ones print their numeric id instead of `UNKNOWN`.
- **`/api/time` range checked (#40)** — only 2020–2100 epochs are accepted, so a typo'd timestamp cannot poison the NTP baseline.

**Size and tooling** — `RAM 22.2 %` (72,884 B of 327,680 B), `Flash 90.3 %` (1,715,375 B of the 1,900,544 B OTA slot, ~185 KB headroom). New checks: `verify_config_ranges.py`, `verify_ubx_parser.py`, `verify_fuel_ohms.py`, `verify_dst_rules.py`, and `make_webui_limits.py` for the WebUI `FIRMWARE_LIMITS` table.

### V1.3.9 — Signed OTA firmware, truthful version identity, hotspot password guard
- **Firmware signing (cloud OTA pull)** — every pulled image is verified against an ECDSA P-256 / SHA-256 signature (`firmware.bin.sig`, a sibling release asset) before `Update.end()` marks the new slot bootable. The public key is compiled in (`include/ota_pubkey.h`, generated by `scripts/ota_sign.py`); the private key stays on the signing machine (`keys/`, gitignored). Missing signature, wrong version or a tampered binary = update refused, current firmware untouched. See *Cloud OTA Pull & Firmware Signing*.
- **TLS is actually verified** — the pull used `setInsecure()`, which accepted any certificate. HTTPS pulls now validate the server against the CA bundle built into the core, and a rejected certificate is logged with the mbedTLS reason instead of looking like a dead server.
- **No resume while signing** — a signature covers the whole image, so a byte-range resume would skip bytes the hash never saw. A stalled signed pull discards the partial slot and restarts from byte 0.
- **One flash session at a time (#24)** — the 15-minute pull-overrun guard used to clear the "busy" latch while the first session still held the OTA slot open, letting a second pull write into the same slot. `Update.begin/abort/end` are now behind an interlock shared by the pull task and the Web UI upload; a reset with a session still open locks OTA until reboot.
- **Web OTA upload hardening (#28)** — uploads are bounded by the real OTA partition size, every `Update.write()` is checked, the session aborts on the first error, and a file that is too small or does not start with a plausible ESP image header is discarded instead of being activated and boot-looping the unit.
- **Version identity is the build, not NVS** — `FW_VERSION` in `src/config.cpp` is the compiled-in truth; the WebUI field is now a display/pull-test label (`VERSION_OVERRIDE`). The manifest's claimed version is no longer written to NVS, so a device can no longer report "up to date" with a firmware it never ran.
- **Boot provenance** — the `bootinfo` namespace records what was running before: `BOOTINFO: firmware v1.3.9 running (previous: 1.3.8)` after an update, plus `build_version` / `version_override` / `previous_version` in `/api/ota/check`.
- **Hotspot password guard (#45)** — an `AP_PASSWORD` of 1–7 characters was rejected by the ESP32 radio, so the config hotspot silently never came up (and the old password stayed in NVS). Short values are now refused with a log line and the default is restored; `WiFi.softAP()` failures are checked and logged; the WebUI warns while the default password is in use.
- Flash usage grows from ~84.7 % to ~88.6 % of the OTA slot (mbedTLS ECDSA/SHA-256 verification code); RAM is unchanged.
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

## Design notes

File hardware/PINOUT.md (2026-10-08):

# Plain-English pinout sheet (drawing aid)

Everything here is read out of the board itself (`hardware/dashboard-plusplus-carrier.kicad_pcb`,
generated by `hardware/scripts/make_pcb.py`). The long technical reference stays in
`README.md` — section *Hardware Pinout Matrix*.

Useful when sketching a new layout: the **label** column is the name used in the code and on
the silkscreen; what you call each block on your drawing is up to you.

## 1. Board frame (fixed geometry)

| Item | Value |
|---|---|
| Board outline | 85.0 × 55.0 mm — KiCad coords x 10→95, y 10→65 |
| View used everywhere | top view: x grows to the right, y grows **down** |
| ESP32 DevKit header rows | near row y = 20.00, far row y = 45.40 (25.4 mm apart), 15 pins each, pitch 2.54 |
| Pin 1 of both rows (square pad) | x = 22.00 — that end is the DevKit's **USB end** |
| DevKit body hanging underneath | x 13.6→67.6, y 18.6→46.8 |
| Antenna keep-out (no copper, any layer) | x 48.96→68.2, y 22.0→43.4 |
| Display socket | along the bottom edge, y = 61.50, pin 1 at x = 25.00 |
| Parts on the **underside** | `J10a`, `J10b` (DevKit sockets), `U4` (LM2596 module) |

## 2. Which block is which

| What it is | label |
|---|---|
| 12 V power plug (XT30) | `J1` |
| fuse holder, 5×20 mm glass fuse | `F1` |
| reverse-polarity / load-dump protection (P-MOS + zener + TVS) | `Q1` `D1` `D2` `R1` `C1` `C2` |
| DC-DC step-down module LM2596, 4 pads, **soldered underneath** | `U4` |
| 5 V output caps by the module | `C3` `C4` |
| ESP32 DevKit sockets (it hangs under the board) | `J10a` = top row, `J10b` = bottom row |
| 4.0" TFT display socket, 16 pins | `J3` |
| GNSS / GPS module plug | `J8` |
| debug / serial plug (TX, RX, GND, 5V) | `J13` |
| spare GPIO plug (6) | `J15` · reset/EN plug (2) | `J16` |
| spare 2×3 plug (5V, GND, ign, GPIO) | `J11` |
| coolant NTC plug | `J5` |
| fuel sender plug | `J7` |
| light sensor (LDR) plug | `J6` |
| speed / hall sensor plug (3 pins) | `J9` |
| ignition +12 plug | `J17` |
| trip-reset: external plug + on-board button | `J14` + `SW1` |
| battery voltage tap (divider) | `R2` `R3` `R4` |
| hall supply selector jumper (5 V / 12 V) | `JP1` |
| isolation optocouplers: ignition, speed | `OK1` `OK2` |
| test points: ignition, speed, battery, fuel | `TP1` `TP2` `TP3` `TP4` |
| spare pad for GPIO0 (nothing connected) | `TP5` |

## 3. ESP32 DevKit sockets

Positions counted from the **USB end** of the dev board (pin 1 = square pad).
Silkscreen note on the board says *CHECK SILK* — clones differ, verify against your module.

**Near row (top, `J10a`)**

| pos | silk | net | used for |
|---|---|---|---|
| 1 | VIN | `V5` | +5 V supply in |
| 2 | GND | `GND` | 0 V |
| 3 | IO13 | `SPARE_D13` | spare |
| 4 | IO12 | `TFT_BL` | display backlight (must be LOW at reset — `R12` pulls it down) |
| 5 | IO14 | `TFT_RST` | display reset |
| 6 | IO27 | `TFT_DC` | display data/command |
| 7 | IO26 | `SPARE_D26` | spare |
| 8 | IO25 | `TRIP_BTN` | trip reset button to GND |
| 9 | IO33 | `HALL` | speed sensor (filtered) |
| 10 | IO32 | `FUEL_SNS` | fuel sender |
| 11 | IO35 | `BAT_SNS` | battery voltage |
| 12 | IO34 | `LDR_SNS` | light sensor |
| 13 | IO39 | — | **not connected** |
| 14 | IO36 | `COOL_SNS` | coolant NTC |
| 15 | EN | `EN` | enable / reset (also on `J16`) |

**Far row (bottom, `J10b`)**

| pos | silk | net | used for |
|---|---|---|---|
| 16 | 3V3 | `V3V3` | 3 V3 out of the DevKit (sensor references) |
| 17 | GND | `GND` | 0 V |
| 18 | IO15 | `SPARE_D15` | spare (strapping pin, header only) |
| 19 | IO2 | `SPARE_D2` | spare |
| 20 | IO4 | `IGN_SENSE` | ignition present (wakes the device) |
| 21 | IO16 | `GPS_RX` | GNSS module TX → ESP |
| 22 | IO17 | `GPS_TX` | ESP → GNSS module RX (idle) |
| 23 | IO5 | `TFT_CS` | display chip select |
| 24 | IO18 | `TFT_SCK` | display clock |
| 25 | IO19 | `SPARE_D19` | spare |
| 26 | IO21 | `SPARE_D21` | spare / I2C SDA (also on `J8`, `J15`) |
| 27 | IO3 | `DBG_RX` | console RX |
| 28 | IO1 | `DBG_TX` | console TX |
| 29 | IO22 | `SPARE_D22` | spare / I2C SCL |
| 30 | IO23 | `TFT_MOSI` | display data in |

## 4. Display socket `J3` (16 pins, pin 1 = VCC, along the bottom edge)

| pin | silk | net | | pin | silk | net |
|---|---|---|---|---|---|---|
| 1 | VCC | `V5` | | 9 | SDO | *(open)* |
| 2 | GND | `GND` | | 10 | T_CLK | *(open)* |
| 3 | CS | `TFT_CS` | | 11 | T_CS | *(open)* |
| 4 | RST | `TFT_RST` | | 12 | T_DIN | *(open)* |
| 5 | DC | `TFT_DC` | | 13 | TPEN | *(open)* |
| 6 | SDI | `TFT_MOSI` | | 14 | T_DO | *(open)* |
| 7 | SCK | `TFT_SCK` | | 15 | SD | *(open)* |
| 8 | LED | `TFT_BL` | | 16 | NC | *(open)* |

Touch and SD pads are deliberately left unconnected (no MISO in the firmware, touch removed in 1.3.6).

## 5. Vehicle & accessory connectors

| label | pins (silk → net) |
|---|---|
| `J1` power in | 1 = `DC_IN` (+12 before fuse) · 2 = `GND` |
| `J9` speed/hall | 1 `+V` = `HALL_VCC` · 2 `SIG` = `HALL_SIG` · 3 `G` = `GND` |
| `J17` ignition | 1 `IGN` = `IGN_12` · 2 `GND` = `GND` |
| `J5` coolant NTC | 1 `SIG` = `COOL_SNS` · 2 `GND` = `GND` |
| `J7` fuel sender | 1 `SIG` = `FUEL_SNS` · 2 `GND` = `GND` |
| `J6` light sensor | 1 `SNS` = `LDR_SNS` · 2 `GND` = `GND` (LDR solders here too) |
| `J14` trip button | 1 `TRIP` = `TRIP_BTN` · 2 `GND` = `GND` |
| `J8` GNSS module | 1 `SDA` = `SPARE_D21` · 2 `SCL` = `SPARE_D22` · 3 `5V` = `V5` · 4 `GND` · 5 `RX` = `GPS_TX` · 6 `TX` = `GPS_RX` |
| `J13` debug | 1 `TX` = `DBG_TX` · 2 `RX` = `DBG_RX` · 3 `GND` · 4 `5V` = `V5` |
| `J15` spare | 1 `D26` · 2 `SDA` · 3 `SCL` · 4 `D19` · 5 `D15` · 6 `GND` |
| `J16` reset | 1 `EN` · 2 `GND` |
| `J11` spare 2×3 | 1 `GND` · 2 `V5` · 3 `SPARE_D26` · 4 `SPARE_D13` · 5 `IGN_12` · 6 `SPARE_D2` |
| `JP1` hall supply | 1 `5V` = `V5` · 2 `SEL` = `HALL_VCC` · 3 `12V` = `DC_12` (jumper picks the sensor supply) |

## 6. Small parts, what each one is for

| label | value | between | purpose |
|---|---|---|---|
| `Q1` | IRF9540N | `MOS_G` `DC_12` `DC_F` | P-MOS high-side, blocks reverse polarity |
| `D1` | BZX55C15V | `MOS_G` `DC_F` | gate zener |
| `R1` | 10 k | `MOS_G` `DC_F` | gate pull-down |
| `D2` | P6KE33A | `DC_12` `GND` | load-dump TVS |
| `C1` | 220 µ/50 V | `DC_12` `GND` | input bulk |
| `C2` | 100 n | `DC_12` `GND` | input HF |
| `C3` | 470 µ/35 V | `V5` `GND` | 5 V bulk |
| `C4` | 100 n | `V5` `GND` | 5 V HF |
| `R2` | 47 k | `DC_12` `BAT_DIV` | battery divider, top |
| `R3` | 10 k | `BAT_DIV` `GND` | battery divider, bottom |
| `R4` | 1 k | `BAT_DIV` `BAT_SNS` | series to the ADC pin |
| `C5` | 100 n | `BAT_SNS` `GND` | filter |
| `R5` | 220 Ω | `V3V3` `FUEL_SNS` | fuel sender excitation |
| `C6` | 100 n | `FUEL_SNS` `GND` | filter |
| `R6` | 10 k | `V3V3` `COOL_SNS` | NTC reference leg |
| `C7` | 100 n | `COOL_SNS` `GND` | filter |
| `R7` | 10 k | `LDR_SNS` `GND` | LDR divider |
| `C8` | 100 n | `LDR_SNS` `GND` | filter |
| `R8` | 1 k | `IGN_12` `IGN_LED` | opto-1 LED series |
| `R9` | 10 k | `IGN_SENSE` `GND` | pull-down |
| `C9` | 100 n | `IGN_SENSE` `GND` | filter |
| `OK1` | PC817B | `IGN_LED` `GND` `IGN_SENSE` `V3V3` | ignition isolation |
| `R10` | 1 k | `HALL_SIG` `HALL_LED` | opto-2 LED series |
| `OK2` | PC817B | `HALL_LED` `GND` `HALL_OUT` `V3V3` | speed-sensor isolation |
| `R11` | 10 k | `HALL_OUT` `GND` | opto-2 pull-down |
| `R13` | 1 k | `HALL_OUT` `HALL` | series to the GPIO |
| `D3` | P6KE6V2 | `HALL` `GND` | clamp on the speed line |
| `C10` | 100 n | `HALL` `GND` | filter |
| `R12` | 10 k | `TFT_BL` `GND` | backlight off at power-up (IO12 strapping) |
| `C11` | 100 n | `TRIP_BTN` `GND` | button debounce |
| `C13` | 100 n | `V3V3` `GND` | reference decoupling |
| `F1` | 5×20 2 A | `DC_IN` `DC_F` | fuse |
| `SW1` | 6 mm tactile | `TRIP_BTN` `GND` | on-board trip reset |
| `TP1`–`TP4` | — | `IGN_SENSE` `HALL` `BAT_SNS` `FUEL_SNS` | test points |
| `TP5` | — | *(no net)* | GPIO0 free pad — the DevKit does not bring IO0 to its headers |

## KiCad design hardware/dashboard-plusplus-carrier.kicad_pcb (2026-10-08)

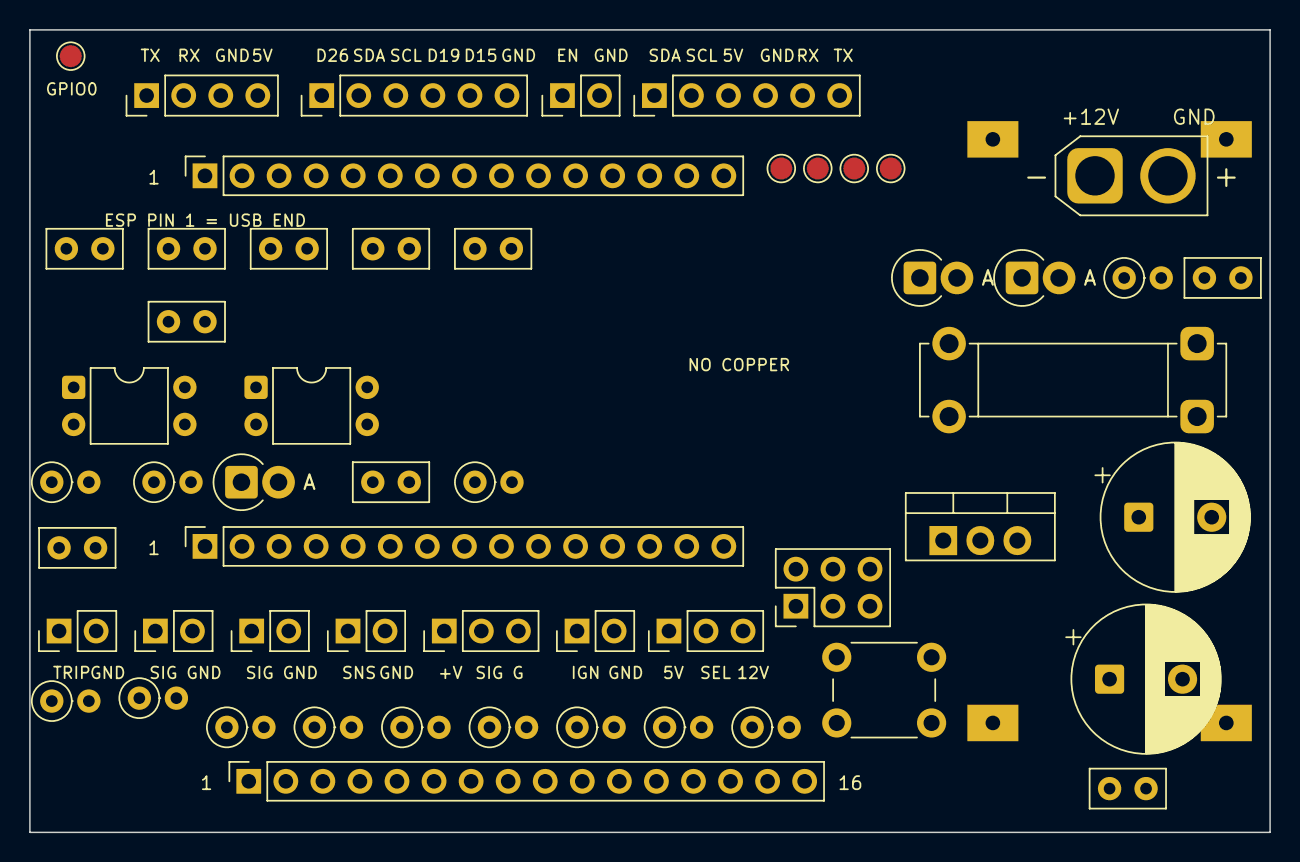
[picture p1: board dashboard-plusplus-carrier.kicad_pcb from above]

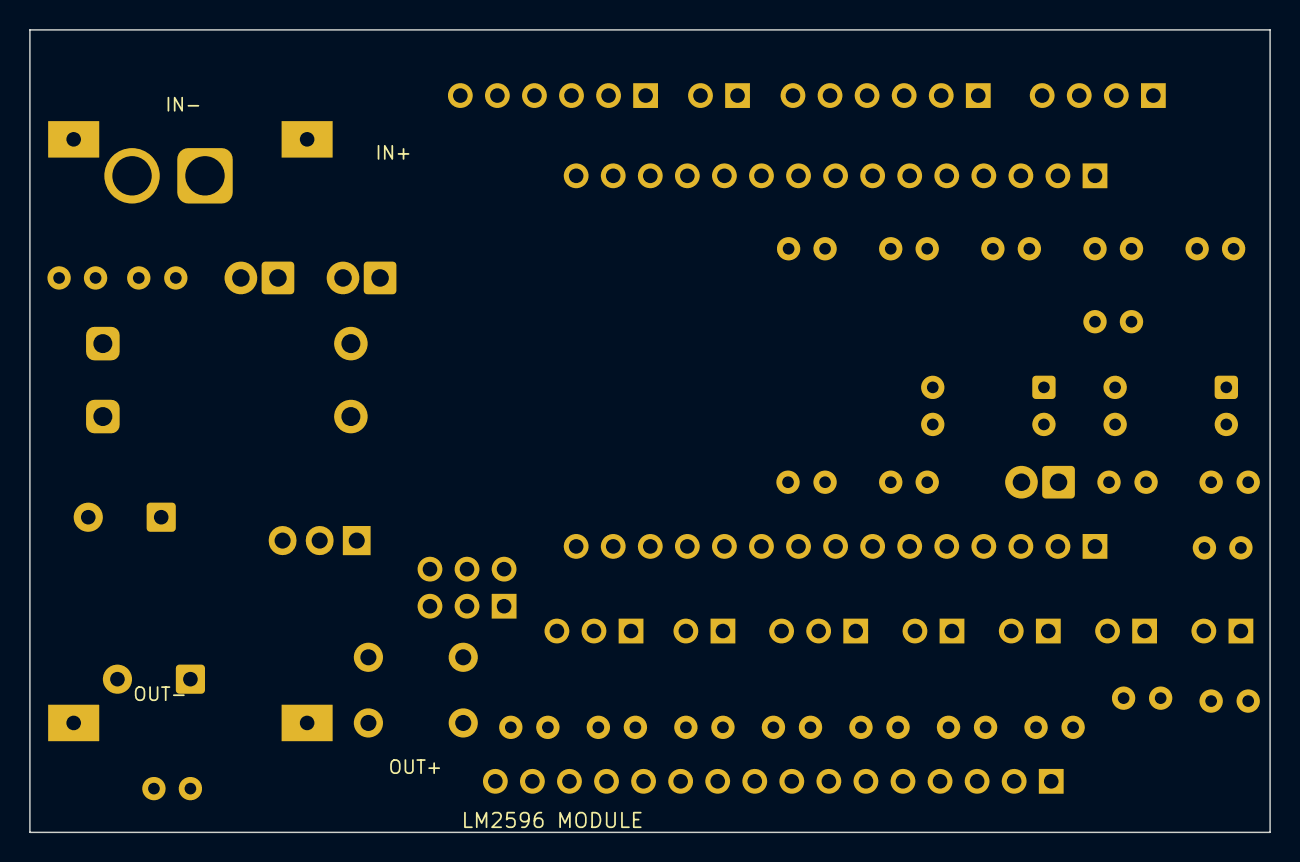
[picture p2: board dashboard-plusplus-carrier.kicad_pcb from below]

Board: 4 copper layers, 85.0 x 55.0 mm, 55 parts (3 on the bottom side), 39 nets, no tracks yet.

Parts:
C1: 220u/50V; CP_Radial_D10.0mm_P5.00mm
C2, C4, C5, C6, C7, C8, C9, C10, C11, C13: 100n; C_Disc_D5.0mm_W2.5mm_P2.50mm
C3: 470u/35V; CP_Radial_D10.0mm_P5.00mm
D1: BZX55C15V; D_DO-15_P2.54mm_Vertical_AnodeUp
D2: P6KE33A; D_DO-15_P2.54mm_Vertical_AnodeUp
D3: P6KE6V2; D_DO-15_P2.54mm_Vertical_AnodeUp
F1: 5x20 2A; Fuseholder_Clip-5x20mm_Littelfuse_521_Lateral_P17.00x5.00mm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
J1: XT30U-M; AMASS_XT30U-M_1x02_P5.0mm_Vertical
J3: TFT-ILI9488; PinSocket_1x16_P2.54mm_Vertical
J5: COOLANT; PinHeader_1x02_P2.54mm_Vertical
J6: LDR; PinHeader_1x02_P2.54mm_Vertical
J7: FUEL; PinHeader_1x02_P2.54mm_Vertical
J8: GPS; PinHeader_1x06_P2.54mm_Vertical
J9: HALL; PinHeader_1x03_P2.54mm_Vertical
J10a: ESP32-DEVKIT-A; PinSocket_1x15_P2.54mm_Vertical
J10b: ESP32-DEVKIT-B; PinSocket_1x15_P2.54mm_Vertical
J11: SMART; PinHeader_2x03_P2.54mm_Vertical
J13: DEBUG; PinHeader_1x04_P2.54mm_Vertical
J14: TRIP; PinHeader_1x02_P2.54mm_Vertical
J15: SPARE; PinHeader_1x06_P2.54mm_Vertical
J16: RESET; PinHeader_1x02_P2.54mm_Vertical
J17: IGNITION; PinHeader_1x02_P2.54mm_Vertical
JP1: HALL +V; PinHeader_1x03_P2.54mm_Vertical
OK1, OK2: PC817B; DIP-4_W7.62mm
Q1: IRF9540N; TO-220-3_Vertical
R1, R3, R6, R7, R9, R11, R12: 10k; R_Axial_DIN0207_L6.3mm_D2.5mm_P2.54mm_Vertical
R2: 47k; R_Axial_DIN0207_L6.3mm_D2.5mm_P2.54mm_Vertical
R4, R8, R10, R13: 1k; R_Axial_DIN0207_L6.3mm_D2.5mm_P2.54mm_Vertical
R5: 220R; R_Axial_DIN0207_L6.3mm_D2.5mm_P2.54mm_Vertical
SW1: TRIP; SW_PUSH_6mm
TP1: IGN_SENSE; TestPoint_Pad_D1.5mm
TP2: HALL; TestPoint_Pad_D1.5mm
TP3: BAT_SNS; TestPoint_Pad_D1.5mm
TP4: FUEL_SNS; TestPoint_Pad_D1.5mm
TP5: GPIO0; TestPoint_Pad_D1.5mm
U4: LM2596-MOD

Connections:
BAT_DIV: R2.2, R3.1, R4.1
BAT_SNS: C5.1, J10a.11, R4.2, TP3.1
COOL_SNS: C7.1, J5.1, J10a.14, R6.2
DBG_RX: J10b.12, J13.2
DBG_TX: J10b.13, J13.1
DC_12: C1.1, C2.1, D2.1, JP1.3, Q1.2, R2.1, U4.1
DC_F: D1.2, F1.2, Q1.3, R1.2
DC_IN: F1.1, J1.1
EN: J10a.15, J16.1
FUEL_SNS: C6.1, J7.1, J10a.10, R5.2, TP4.1
GND: C1.2, C2.2, C3.2, C4.2, C5.2, C6.2, C7.2, C8.2, C9.2, C10.2, C11.2, C13.2, D2.2, D3.2, J1.2, J3.2, J5.2, J6.2, J7.2, J8.4, J9.3, J10a.2, J10b.2, J11.1, J13.3, J14.2, J15.6, J16.2, J17.2, OK1.2, OK2.2, R3.2, R7.2, R9.2, R11.2, R12.2, U4.2, U4.4
GPS_RX: J8.6, J10b.6
GPS_TX: J8.5, J10b.7
HALL: C10.1, D3.1, J10a.9, R13.2, TP2.1
HALL_LED: OK2.1, R10.2
HALL_OUT: OK2.3, R11.1, R13.1
HALL_SIG: J9.2, R10.1
HALL_VCC: J9.1, JP1.2
IGN_12: J11.5, J17.1, R8.1
IGN_LED: OK1.1, R8.2
IGN_SENSE: C9.1, J10b.5, OK1.3, R9.1, TP1.1
LDR_SNS: C8.1, J6.1, J10a.12, R7.1
MOS_G: D1.1, Q1.1, R1.1
SPARE_D2: J10b.4, J11.6
SPARE_D13: J10a.3, J11.4
SPARE_D15: J10b.3, J15.5
SPARE_D19: J10b.10, J15.4
SPARE_D21: J8.1, J10b.11, J15.2
SPARE_D22: J8.2, J10b.14, J15.3
SPARE_D26: J10a.7, J11.3, J15.1
TFT_BL: J3.8, J10a.4, R12.1
TFT_CS: J3.3, J10b.8
TFT_DC: J3.5, J10a.6
TFT_MOSI: J3.6, J10b.15
TFT_RST: J3.4, J10a.5
TFT_SCK: J3.7, J10b.9
TRIP_BTN: C11.1, J10a.8, J14.1, SW1.1, SW1.2
V3V3: C13.1, J10b.1, OK1.4, OK2.4, R5.1, R6.1
V5: C3.1, C4.1, J3.1, J8.3, J10a.1, J11.2, J13.4, JP1.1, U4.3

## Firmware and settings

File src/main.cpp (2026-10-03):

#include "dashboard.h"
#include "bootinfo.h"
#include <stdarg.h>

char logBuf[LOG_BUF_SIZE];
volatile int logHead = 0;
volatile int logTail = 0;
volatile unsigned long logSequence = 0;
portMUX_TYPE logMux = portMUX_INITIALIZER_UNLOCKED;

unsigned long g_startupTime = 0;
bool forceFullRedraw = false;

// Rolling worst inter-frame gap (ms), reset by the heartbeat every 10s. >18ms
// on a 60fps dashboard is a visible frame-drop; this catches the sub-33ms
// jitter that the SLOW FRAME diagnostic (>33ms threshold) misses.
volatile unsigned long g_diagMaxFrameMs = 0;
volatile unsigned long g_diagOver24Ms = 0;
volatile unsigned long g_diagMaxSensorGapMs = 0;
volatile bool pendingSleep = false;
volatile bool pendingReboot = false;
volatile bool otaUpdateInProgress = false;
volatile bool pendingOtaScreen = false;

bool pendingInvertDisplay = false;
int pendingBacklightValue = -1;
int currentBrightnessTarget = 0;

// The backlight LEDC channel is 8-bit (ledcAttach(BL_DISPLAY, 1000, 8)) while
// every caller works in percent. Before this, percent->duty was open-coded in
// four places and nothing limited it: a BACKLIGHT_BRIGHTNESS outside 0..100
// (an old NVS write, or a POST that bypassed validation) reached ledcWrite
// directly - a negative value wrapped to a huge duty and left the panel dark at
// boot with no explanation (issue #20). One conversion, one writer.
int backlightDuty(int percent) {
  if (percent < 0 || percent > 100) {
    logPrintf("Backlight: %d%% outside [0..100], clamped\n", percent);
    percent = constrain(percent, 0, 100);
  }
  return (percent * 255) / 100;
}

// The only place that drives the backlight channel directly. Also keeps
// currentBrightnessTarget in step, so the sleep/wake and splash fades ramp to
// the level the panel is actually at. Callers that fade gradually (splash,
// auto-brightness) set the target through backlightDuty() and write themselves.
void applyBacklight(int percent) {
  int duty = backlightDuty(percent);
  currentBrightnessTarget = duty;
  ledcWrite(BL_DISPLAY, duty);
}

// Config-save handoff (issue #10): the web task parses and writes the config,
// the display loop applies the panel-bus and CPU-frequency changes at a frame
// gap, and no frame is painted while the parameter group is being rewritten.
volatile bool pendingApplyBusConfig = false;
volatile bool pendingCpuReeval = false;
volatile bool configSaveInProgress = false;
volatile unsigned long configSaveStartMs = 0;

// Web-task watchdog state: disarmed when the device shows a fast-reboot loop
// so a watchdog can't brick the device by restarting it forever.
static bool watchdogDisabled = false;

// CPU busy probes: one task per core. Each probe increments its counter once
// per 1 ms tick slot in which its core ran nothing higher-priority, so
// (1 - ticks/elapsedMs) is the fraction of time the core was busy. (ccount
// cannot measure this: it ticks at the fixed XTAL rate regardless of load.)
static volatile uint32_t cpuProbeTicks[2] = {0, 0};

static void cpuProbeTask(void *pv) {
  int core = (int)(intptr_t)pv;
  for (;;) {
    cpuProbeTicks[core] = cpuProbeTicks[core] + 1;
    vTaskDelay(1);
  }
}

void logPrintf(const char *fmt, ...) {
  char tmp[256];
  va_list args;
  va_start(args, fmt);
  int len = vsnprintf(tmp, sizeof(tmp), fmt, args);
  va_end(args);
  if (len > 0) {
    // Shared by every task (main/web/gps/sensor) plus the /api/serial
    // reader - guard the ring so two writers can't tear a line and the
    // reader never sees a half-written window. Serial print stays OUTSIDE
    // the critical section (UART TX is slow; keep the lock window tiny).
    portENTER_CRITICAL(&logMux);
    for (int i = 0; i < len && i < 256; i++) {
      logBuf[logHead] = tmp[i];
      logHead = (logHead + 1) % LOG_BUF_SIZE;
      if (logHead == logTail)
        logTail = (logTail + 1) % LOG_BUF_SIZE;
    }
    logSequence = logSequence + 1;
    portEXIT_CRITICAL(&logMux);
    Serial.print(tmp);
  }
}

// Task handles, kept for one purpose only: /api/perf reports the FreeRTOS stack
// high-water mark of each task (issue #27). Nothing else uses them.
TaskHandle_t sensorTaskHandle = NULL;
TaskHandle_t gpsTaskHandle = NULL;
TaskHandle_t webTaskHandle = NULL;

// Issue #25: xTaskCreatePinnedToCore returns errCOULD_NOT_ALLOCATE_REQUIRED_MEMORY
// when the heap is tight, and that result used to be thrown away. A task that never
// started was invisible - you only noticed later as a frozen heartbeat, no Web UI or
// dead sensors. Now every start is checked, retried once on half the requested stack
// (a reduced stack is usually enough and beats a missing subsystem), and recorded in
// failedTasksMask so the boot log names exactly what is missing.
static uint8_t failedTasksMask = 0; // bit0 sensor, bit1 gps, bit2 web, bits3-4 probes

static bool startTask(const char *name, TaskFunction_t fn, uint32_t stackBytes,
                      UBaseType_t prio, BaseType_t core, void *param,
                      TaskHandle_t *outHandle, uint8_t failBit) {
  if (xTaskCreatePinnedToCore(fn, name, stackBytes, param, prio, outHandle,
                             core) == pdPASS)
    return true;
  logPrintf("Task %s: no room for a %lu B stack (free heap %lu) - retrying at %lu B\n",
            name, (unsigned long)stackBytes, (unsigned long)ESP.getFreeHeap(),
            (unsigned long)(stackBytes / 2));
  if (xTaskCreatePinnedToCore(fn, name, stackBytes / 2, param, prio, outHandle,
                             core) == pdPASS) {
    logPrintf("Task %s started on the reduced stack\n", name);
    return true;
  }
  failedTasksMask |= (1u << failBit);
  logPrintf("Task %s FAILED to start (free heap %lu) - that subsystem is offline this session\n",
            name, (unsigned long)ESP.getFreeHeap());
  return false;
}

// setCpuFrequencyMhz() returns false when the switch is refused (unsupported
// value, PLL/APB conflict). The config layer already snaps MANUAL_CPU_FREQ to
// 80/160/240 (issue #21), but the call can still fail - and logging the new
// frequency without checking the result is how "it says 240MHz but runs at 80"
// bug reports start (issue #34).
static bool applyCpuFreq(int mhz, const char *why) {
  if (setCpuFrequencyMhz(mhz)) return true;
  logPrintf("CPU: refused to switch to %dMHz (%s) - still running at %dMHz\n",
            mhz, why, (int)getCpuFrequencyMhz());
  return false;
}

void setup() {
  applyCpuFreq(240, "boot");
  Serial.setTxBufferSize(256);
  // arduino-esp32 3.x moved the UART1 console default to GPIO26/27 - pin it
  // explicitly to GPIO1/3 (the device's console wiring) to keep 2.x behavior.
  Serial.setPins(1, 3);
  Serial.begin(115200);
  delay(50);

  processConfig(0);
  // Factory-default seeding (supersedes the CFG_VER 1..4 migrations): any
  // unit whose config has not yet been seeded (CFG_VER < 5, including a
  // brand-new NVS) adopts the dashboard_backup.json values — first boot
  // behaves like a factory reset, and a previously configured unit gets the
  // reference backup applied once (CFG_VER -> 5). The historical v2/v3/v4
  // one-shot fixes (80 MHz SPI, dynamic CPU off, 60 FPS) are all covered by
  // the factory values, so the old migration chain is no longer needed.
  {
    NvsSession session("cfg", false);
    int cfgVer = -1;
    if (session.opened()) cfgVer = session.nvs.getInt("CFG_VER", -1);
    // If NVS could not be opened, seeding would overwrite a configured unit
    // with factory defaults - the opposite of a recovery. Skip instead.
    if (!session.opened())
      logPrintf("Config: NVS unreadable at boot - factory seeding skipped\n");
    else if (cfgVer < 5)
      seedNVSWithFactoryDefaults();
  }
  recalculateDerivedParams();
  logStoredWifiProfiles();

  // Recovery + watchdog guard:
  // - Serial "RESET" within the first 2s after boot: factory reset (NVS wipe).
  // - Hold BOOT (GPIO0) for 8s within the first 30s after boot: factory reset.
  // - Track fast reboot loops (RTC memory survives ESP.restart) so the
  //   web-task watchdog can never brick the device by rebooting it forever.
  // Boot/reboot forensics (Phase 0): reset reason, last-reboot tag, and the
  // fast-reboot-storm latch now live in bootinfo.cpp (bootinfo.h). A storm
  // still disables the web watchdog (as before) AND is exposed to the rest of
  // the firmware so clean auto-reboots can be *broken*, not just delayed.
  pinMode(0, INPUT_PULLUP);
  bootinfo_init();
  if (bootinfo_storm_active()) {
    watchdogDisabled = true;
    logPrintf("Warning: %u fast reboots in 2 min, auto-reboots suppressed for this boot\n",
              bootinfo_boot_count());
  }
  {
    unsigned long resetDeadline = millis() + 2000;
    // Rolling window, not an accumulating capture (issue #39): the boot banner,
    // log echo and any line-noise can pour well over 256 characters into UART0
    // inside this 2 s window, and a capture buffer that hits its limit stops
    // accepting input - so a later "RESET" could never match. Only the most
    // recent characters can answer the question "did RESET just arrive?", and
    // 32 bytes costs nothing.
    char bootWindow[32];
    int bootWindowLen = 0;
    bootWindow[0] = 0;
    while (millis() < resetDeadline) {
      while (Serial.available()) {
        char c = (char)Serial.read();
        if (bootWindowLen < (int)sizeof(bootWindow) - 1) {
          bootWindow[bootWindowLen++] = c;
        } else {
          memmove(bootWindow, bootWindow + 1, (size_t)bootWindowLen);
          bootWindow[bootWindowLen - 1] = c;
        }
        bootWindow[bootWindowLen] = 0;
        if (strstr(bootWindow, "RESET")) {
          logPrintf("Serial factory reset command received\n");
          factoryResetConfig();
          logPrintf("Factory reset done, rebooting\n");
          delay(100);
          bootinfo_tag_reboot("factory-reset");
          ESP.restart();
        }
      }
      delay(10);
    }
  }

  display.applyBusConfig();

  if (!ENABLE_DYNAMIC_CPU) {
    applyCpuFreq(MANUAL_CPU_FREQ, "manual mode");
  }

  logPrintf("Starting Dashboard++\n");

  g_stateMutex = xSemaphoreCreateMutex();
  if (g_stateMutex == NULL) {
    logPrintf("*** FATAL: g_stateMutex allocation failed ***\n");
    ESP.restart();
  }
  prefsMux = xSemaphoreCreateMutex();
  if (prefsMux == NULL) {
    logPrintf("*** FATAL: prefsMux allocation failed ***\n");
    ESP.restart();
  }
  gpsFixMux = xSemaphoreCreateMutex();
  if (gpsFixMux == NULL) {
    logPrintf("*** FATAL: gpsFixMux allocation failed ***\n");
    ESP.restart();
  }
  pinMode(CS_DISPLAY, OUTPUT);
  digitalWrite(CS_DISPLAY, HIGH);
  // arduino-esp32 3.x: ledcSetup/ledcAttachPin are gone - ledcAttach merges them
  // (first arg is the pin, returns bool; the channel is allocated internally).
  // Pin BL_DISPLAY = GPIO12.
  bool _ledcOk = ledcAttach(BL_DISPLAY, 1000, 8);
  logPrintf("ledcAttach pin=%d ok=%d\n", BL_DISPLAY, (int)_ledcOk);
  if (!_ledcOk) logPrintf("*** LEDC SETUP FAILED ***\n");
  ledcWrite(BL_DISPLAY, 0);
  pinMode(SPI_RST, OUTPUT);
  digitalWrite(SPI_RST, LOW);
  delay(10);
  digitalWrite(SPI_RST, HIGH);
  delay(20);

  pinMode(POWER_SENSE_PIN, INPUT);
  pinMode(BATTERY_SENSE_PIN, INPUT);
  pinMode(TEMP_SENSE_PIN, INPUT);
  analogSetAttenuation(ADC_11db);
  pinMode(HALL_SENSOR_PIN, INPUT_PULLUP);
  // CHANGE, not FALLING (issue #30): the pulse width is measured from the
  // fall/rise pair instead of being sampled after a busy-wait inside the ISR.
  attachInterrupt(digitalPinToInterrupt(HALL_SENSOR_PIN), hallSensorISR,
                  CHANGE);
  initFuelSensor();
  pinMode(LIGHT_SENSOR_PIN, INPUT);
  // Physical trip-reset button to GND (issue #17); the internal pull-up keeps
  // the line high when nothing is pressed.
  pinMode(TRIP_RESET_PIN, INPUT_PULLUP);

  logPrintf("display.init() start\n");
  bool initOk = display.init();
  logPrintf("display.init() done ok=%d\n", (int)initOk);
  display.setRotation(DISPLAY_ROTATION);
  logPrintf("setRotation done\n");

  initFilesystem();

  for (int i = 0; i < 5; i++) {
    processLightSensor();
    delay(5);
  }
  if (ENABLE_AUTO_BRIGHTNESS) {
    int dVal = LIGHT_SENSOR_DARK_VAL;
    int bVal = LIGHT_SENSOR_BRIGHT_VAL;
    if (bVal != dVal) {
      float t = (filteredAmbientValue - (float)dVal) / (float)(bVal - dVal);
      t = constrain(t, 0.0f, 1.0f);
      int pct = AUTO_BRIGHT_DARK + (int)((AUTO_BRIGHT_LIGHT - AUTO_BRIGHT_DARK) * t);
      pct = constrain(pct, 0, 100);
      currentBrightnessTarget = backlightDuty(pct);
    } else {
      currentBrightnessTarget = backlightDuty(BACKLIGHT_BRIGHTNESS);
    }
  } else {
    currentBrightnessTarget = backlightDuty(BACKLIGHT_BRIGHTNESS);
  }
  // currentBrightnessTarget is always 0..255 now, so a 0 setting is simply a
  // dark panel: the fade loop below still runs its single step instead of
  // looking like a dead display.

  drawSplashBase();
  logPrintf("drawSplashBase done\n");
  logPrintf("splash fade: currentBrightnessTarget=%d\n", currentBrightnessTarget);
  int fadeStepCount = (currentBrightnessTarget / 8) + 1;
  for (int level = 0; level <= currentBrightnessTarget; level += 8) {
    ledcWrite(BL_DISPLAY, level);
    logPrintf("  fade step: level=%d\n", level);
    delay(FADE_DURATION_MS / fadeStepCount);
  }
  ledcWrite(BL_DISPLAY, currentBrightnessTarget);
  logPrintf("  fade final: value=%d\n", currentBrightnessTarget);
  updateSplashProgress(20);

  gpsSerial.begin(GPS_BAUD, SERIAL_8N1, GNSS_UART2_RX_PIN, GNSS_UART2_TX_PIN);
  gpsSerial.setTimeout(20);
  delay(100);
  configureGNSS();

  updateSplashProgress(40);

  if (prefsMux)
    xSemaphoreTake(prefsMux, portMAX_DELAY);
  preferences.begin("dashboard", false);
  double odoBoot = preferences.getDouble("odo", 0.0);
  preferences.end();
  odoSet(odoBoot);
  odoMarkSaved(odoBoot);
  if (prefsMux)
    xSemaphoreGive(prefsMux);

  updateSplashProgress(60);
  for (int i = 0; i < 10; i++) {
    processFuelSensor();
    processBatterySensor();
    processTemperatureSensor();
    delay(10);
    updateSplashProgress(60 + (i * 3));
  }
  updateSplashProgress(100);
  delay(50);

  fadeStepCount = (currentBrightnessTarget / 8) + 1;
  for (int level = currentBrightnessTarget; level >= 0; level -= 8) {
    ledcWrite(BL_DISPLAY, level);
    delay(FADE_DURATION_MS / fadeStepCount);
  }
  ledcWrite(BL_DISPLAY, 0);
  display.fillScreen(TFT_BLACK);
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
void loop() {
  if (pendingSleep)
    showGoodbyeScreen(true);
  if (pendingReboot)
    showGoodbyeScreen(false);

  if (pendingInvertDisplay) {
    display.invertDisplay(DISPLAY_INVERT_COLORS);
    pendingInvertDisplay = false;
  }
  if (pendingBacklightValue >= 0) {
    applyBacklight(pendingBacklightValue);
    pendingBacklightValue = -1;
  }

  if (ENABLE_AUTO_BRIGHTNESS) {
    static int autoBrightTarget = -1;
    static float autoBrightPwmF = -1.0f;
    static unsigned long lastAutoBrightMs = 0;
    unsigned long abNow = millis();
    if (abNow - lastAutoBrightMs >= 500) {
      lastAutoBrightMs = abNow;
      int dVal = LIGHT_SENSOR_DARK_VAL;
      int bVal = LIGHT_SENSOR_BRIGHT_VAL;
      if (bVal != dVal) {
        float t = (filteredAmbientValue - (float)dVal) / (float)(bVal - dVal);
        t = constrain(t, 0.0f, 1.0f);
        int pct = AUTO_BRIGHT_DARK + (int)((AUTO_BRIGHT_LIGHT - AUTO_BRIGHT_DARK) * t);
        pct = constrain(pct, 0, 100);
        autoBrightTarget = backlightDuty(pct);
        if (autoBrightPwmF < 0.0f) autoBrightPwmF = (float)autoBrightTarget;
      }
    }
    if (autoBrightTarget >= 0) {
      currentBrightnessTarget = autoBrightTarget;
      float alpha = 1.0f - expf(-(float)DISPLAY_REFRESH_MS / (float)AUTO_BRIGHT_FADE_MS);
      autoBrightPwmF += ((float)autoBrightTarget - autoBrightPwmF) * alpha;
      if (abs(autoBrightTarget - (int)autoBrightPwmF) <= 1)
        autoBrightPwmF = (float)autoBrightTarget;
      // autoBrightPwmF is a smoothed *duty* (not a percent), so it cannot go
      // through applyBacklight(); the constrain keeps it inside the 8-bit range
      // the channel was configured with (issue #20).
      ledcWrite(BL_DISPLAY, constrain((int)autoBrightPwmF, 0, 255));
    }
  }

  unsigned long now = millis();

  // Diagnostic build markers: verifies the new firmware is running and gives a
  // rolling baseline (boot banner once, heartbeat every 10s).
  static bool diagBannerLogged = false;
  if (!diagBannerLogged) {
    diagBannerLogged = true;
    logPrintf("DIAG BUILD v15: freq=%uMHz fpsTarget=%u heap=%lu\n",
              getCpuFrequencyMhz(), TARGET_FPS, (unsigned long)ESP.getFreeHeap());
  }
  static unsigned long lastDiagHeartbeat = 0;
  if (now - lastDiagHeartbeat >= 10000) {
    lastDiagHeartbeat = now;
    logPrintf("HB: up=%lus fps=%.1f freq=%uMHz tgtFps=%d heap=%lu min=%lu maxAlloc=%lu sp=%d fallback=%d otaReq=%d memAct=%d wifi=%d rssi=%d sta=%d/%d/%u apClients=%u temp=%.1f maxFrame=%lums over24=%lu sMaxGap=%lums\n",
              millis() / 1000UL, (double)currentMeasuredFps,
              (unsigned)getCpuFrequencyMhz(), TARGET_FPS,
              (unsigned long)ESP.getFreeHeap(), (unsigned long)ESP.getMinFreeHeap(),
              (unsigned long)ESP.getMaxAllocHeap(), (int)speedSpriteValid(),
              (int)isSpeedFallback(),
              (int)otaMemReleaseRequested, (int)memSaverActive,
              (int)WiFi.status(), (int)WiFi.RSSI(),
              (int)staDbgPhase, staDbgNetIdx, (unsigned)staDbgReason,
              (unsigned)WiFi.softAPgetStationNum(), (double)temperatureRead(),
              (unsigned long)g_diagMaxFrameMs, (unsigned long)g_diagOver24Ms,
              (unsigned long)g_diagMaxSensorGapMs);
    g_diagMaxFrameMs = 0;
    g_diagOver24Ms = 0;
    g_diagMaxSensorGapMs = 0;
  }

  // Diagnostic: log OTA/mem-saver state transitions and any loop stall >50ms.
  // Logs only on change/anomaly so steady-state operation stays silent.
  static bool tOtaReq = false, tOtaRel = false, tMemReq = false, tMemAct = false,
              tOtaUp = false;
  if (otaMemReleaseRequested != tOtaReq || otaMemReleased != tOtaRel ||
      memSaverRequested != tMemReq || memSaverActive != tMemAct ||
      otaUpdateInProgress != tOtaUp) {
    tOtaReq = otaMemReleaseRequested;
    tOtaRel = otaMemReleased;
    tMemReq = memSaverRequested;
    tMemAct = memSaverActive;
    tOtaUp = otaUpdateInProgress;
    logPrintf("STATE: otaReq=%d otaRel=%d memReq=%d memAct=%d otaUp=%d heap=%lu\n",
              (int)tOtaReq, (int)tOtaRel, (int)tMemReq, (int)tMemAct, (int)tOtaUp,
              (unsigned long)ESP.getFreeHeap());
  }
  static unsigned long lastLoopEntryMs = 0;
  if (lastLoopEntryMs != 0) {
    unsigned long loopGap = now - lastLoopEntryMs;
    if (loopGap > 50)
      logPrintf("STALL: loop gap %lums heap=%lu otaReq=%d memAct=%d webCount=%lu rssi=%d\n",
                (unsigned long)loopGap, (unsigned long)ESP.getFreeHeap(),
                (int)otaMemReleaseRequested, (int)memSaverActive,
                (unsigned long)webLoopCount, (int)WiFi.RSSI());
  }
  lastLoopEntryMs = now;

  // Frees the speed sprite when an OTA check is pending (safe point: no sprite
  // is in use between frames). Must run before any TLS work starts.
  processOtaMemRelease();

  // Same release triggered by the web task when free heap gets critically low,
  // so the big UI buffers never starve the /api/config handler or TLS stack.
  processMemSaverRelease();

  // Bus / CPU-frequency changes requested by the config-save handler, applied at
  // the safe point between frames (issue #10).
  processConfigApply();

  // Rebuilds the speed sprite dropped by either release above. Runs here, at a
  // safe point between frames, so the VLW parse + allocation never stalls a
  // draw frame (previously it ran mid-frame on the next speed change).
  ensureSpeedSprite();

  // A config save rewrites ~90 parameters as a group (layout geometry, offsets,
  // digit counts). Painting while that write is in flight can capture a
  // half-old/half-new set, so the screen keeps the previous frame until the
  // writer is done. Bounded, and non-blocking, so a writer that never clears
  // the flag cannot freeze the display.
  if (configSaveInProgress && (millis() - configSaveStartMs) < 2000) return;

  SensorSnapshot snap;
  if (xSemaphoreTake(g_stateMutex, pdMS_TO_TICKS(5)) == pdTRUE) {
    snap = g_sensorData;
    xSemaphoreGive(g_stateMutex);
  }
  // Refresh the clock/date from the system clock directly (the sensor task
  // keeps it synced from GPS/NTP; in demo mode the simulated GPS time is
  // never applied, so this is always the real clock). If the sensor task is
  // stalled by core-0 network work the on-screen clock keeps ticking.
  {
    int hh, mm, dd, mo, yy;
    if (systemTimeToLocal(hh, mm, dd, mo, yy)) {
      snap.localHour = hh;
      snap.minute = mm;
      snap.day = dd;
      snap.month = mo;
      snap.year = yy;
      snap.timeValid = true;
      snap.dateValid = true;
    } else if (ENABLE_DEMO_MODE) {
      // Demo without a synced clock: fall back to a simulated wall clock so
      // the demo still shows time/date.
      unsigned long s = 10UL * 3600UL + millis() / 1000UL;
      snap.localHour = (s / 3600) % 24;
      snap.minute = (s / 60) % 60;
      snap.day = 16;
      snap.month = 7;
      snap.year = 26;
      snap.timeValid = true;
      snap.dateValid = true;
    }
  }
  // Sensor-task heartbeat: the loop never stalls (HB proves it), so a stalled
  // sensor task is invisible without a dedicated tick watch. Track the max
  // gap between sensor ticks; printed in the HB as sMaxGap=.
  static unsigned long lastSensorTickSeen = 0;
  if (g_sensorLastTickMs != lastSensorTickSeen) {
    if (lastSensorTickSeen != 0) {
      unsigned long gap = g_sensorLastTickMs - lastSensorTickSeen;
      if (gap > g_diagMaxSensorGapMs) g_diagMaxSensorGapMs = gap;
    }
    lastSensorTickSeen = g_sensorLastTickMs;
  }
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

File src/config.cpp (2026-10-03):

#include "dashboard.h"
#include <nvs.h>  // nvs_get_stats: the partition's entry budget, for failed writes

// ----------------------------------------------------------------------------
// Configuration variables (defined here, declared extern elsewhere)
// ----------------------------------------------------------------------------
int DISPLAY_ROTATION = 1;
bool UNITS_IMPERIAL = false;

char SPLASH_SIGNATURE[48] = "by @ale.finot";
char REBOOT_SIGNATURE[48] = "Dashboard++ by @ale.finot";
char DASHBOARD_SIGNATURE[96] = "<<<<<<    Dashboard++ by @ale.finot    >>>>>>";

int TEMP_BAR_MIN = 10;
int TEMP_BAR_MAX = 110;
int TEMP_WARN_RED = 90;
int TEMP_WARN_YEL = 45;
int TEMP_WARN_LOW = 20;
int FUEL_WARN_RED = 20;
int FUEL_WARN_YEL = 45;

char COLOR_TEMP_NORM[8] = "#00ff00";
char COLOR_TEMP_WARN[8] = "#ffff00";
char COLOR_TEMP_CRIT[8] = "#ff0000";

char COLOR_FUEL_NORM[8] = "#00ff00";
char COLOR_FUEL_WARN[8] = "#ffff00";
char COLOR_FUEL_CRIT[8] = "#ff0000";

uint16_t c_temp_norm, c_temp_warn, c_temp_crit;
uint16_t c_fuel_norm, c_fuel_warn, c_fuel_crit;
char GHOST_COLOR_STR[8] = "#474747";
uint16_t ghost_color;

uint32_t SPI_BUS_SPEED = 60000000;
int DISPLAY_WIDTH = 480;
int DISPLAY_HEIGHT = 320;

int BIG_CENTER_X = 240;
int BIG_CENTER_Y = 160;

float WHEEL_CIRCUMFERENCE_MM = 1650.0f;
float FUEL_FILTER_ALPHA = 0.08f;
// How long the physical trip-reset button must be held, in ms (issue #17).
int TRIP_RESET_HOLD_MS = 1500;

float NTC_R_BALANCE = 10000.0f;
float NTC_R25 = 10000.0f;
float NTC_BETA = 3950.0f;
float NTC_TEMP_OFFSET = 0.0f;
float BATTERY_SCALE = 5.7f;
float BATTERY_OFFSET = 0.2f;

int GPS_BAUD = 115200;
int MIN_SATELLITES = 8;
int OPTIMAL_SATELLITES = 12;
float MAX_SPEED_DELTA_KMH = 5.0f;
float MIN_SPEED_THRESHOLD = 1.0f;
float GPS_START_KMH = 3.0f;
int GPS_STOP_SETTLE_MS = 1500;
float GPS_MIN_DEV_KMH = 1.0f;
// 0 = Hall only, 1 = GPS only, 2 = Sensor fusion (default). Replaces GPS_ONLY_MODE.
int SPEED_SOURCE_MODE = 2;
int SPEED_SOURCE_HOLD_MS = 500;
int HALL_MEDIAN_SAMPLES = 3;
// 8x keeps single EMI blips out (a 30 ms blip is ~10x the 297 ms period at 20 km/h);
// real driving shifts the period <2%/rotation, so 8x never rejects a real pulse.
int HALL_PERIOD_GUARD = 8;
// Pulse-width qualification window (Layer 1): after a FALLING edge the ISR
// waits this long and re-samples the pin. A genuine magnet pass is LOW for
// hundreds of microseconds (one revolution at 200 km/h is 29.7 ms), while
// spark-plug EMI rings and collapses back HIGH in <10 us, so 150 us rejects
// ignition noise with an order of magnitude of physical margin to spare.
int HALL_PULSE_MIN_US = 150;
float ACCEL_START_SPEED = 1.0f;
float ACCEL_TARGET_SPEED = 50.0f;
float ACCEL_MAX_TIME = 9.99f;
char ACCEL_BADGE_LINE1[16] = "0-50";
char ACCEL_BADGE_LINE2[16] = "km/h";

int OFFSET_BIG_TIME_X = 107;
int OFFSET_BIG_TIME_Y = -91;
int OFFSET_BIG_DATE_X = -131;
int OFFSET_BIG_DATE_Y = -91;
int OFFSET_BIG_SIGNATURE_X = 0;
int OFFSET_BIG_SIGNATURE_Y = -75;
int OFFSET_BIG_SPEED_NUM_X = 0;
int OFFSET_BIG_SPEED_NUM_Y = -3;
int OFFSET_BIG_SPEED_UNIT_X = 106;
int OFFSET_BIG_SPEED_UNIT_Y = 56;
int OFFSET_BIG_ODO_X = 22;
int OFFSET_BIG_ODO_Y = 126;
int OFFSET_BIG_SAT_X = 179;
int OFFSET_BIG_SAT_Y = -114;
int OFFSET_BIG_TMR_X = -53;
int OFFSET_BIG_TMR_Y = -46;
int OFFSET_BIG_BAT_X = -112;
int OFFSET_BIG_BAT_Y = 123;

int SIDEBAR_LEFT_X = 10;
int SIDEBAR_LEFT_Y = 95;
int SIDEBAR_RIGHT_X = 462;
int SIDEBAR_RIGHT_Y = 95;
int SIDEBAR_BAR_WIDTH = 8;
int SIDEBAR_BAR_HEIGHT = 190;

int OFFSET_HALL_ICON_X = 0;
int OFFSET_HALL_ICON_Y = -100;
int OFFSET_WIFI_ICON_X = 204;
int OFFSET_WIFI_ICON_Y = -108;
int OFFSET_INST_KML_X = 60;
int OFFSET_INST_KML_Y = -25;
int OFFSET_AVG_KML_X = 160;
int OFFSET_AVG_KML_Y = -25;
int OFFSET_AVG_SPEED_X = -163;
int OFFSET_AVG_SPEED_Y = -25;
int OFFSET_MAX_SPEED_X = -60;
int OFFSET_MAX_SPEED_Y = -25;
int OFFSET_FUEL_LTRS_X = 132;
int OFFSET_FUEL_LTRS_Y = 123;

int ALIGN_BIG_SPEED_NUM = ALIGN_CENTER;
int ALIGN_BIG_SAT = ALIGN_CENTER;
int ALIGN_BIG_TMR = ALIGN_CENTER;
int ALIGN_BIG_BAT = ALIGN_CENTER;
int ALIGN_INST_KML = ALIGN_CENTER;
int ALIGN_AVG_KML = ALIGN_CENTER;
int ALIGN_AVG_SPEED = ALIGN_CENTER;
int ALIGN_MAX_SPEED = ALIGN_CENTER;
int ALIGN_FUEL_LTRS = ALIGN_CENTER;
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

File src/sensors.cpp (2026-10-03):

#include "dashboard.h"
#include "esp_rom_sys.h"
#include "driver/gpio.h"
#include "soc/gpio_reg.h"

TinyGPSPlus gps;
HardwareSerial gpsSerial(2);

static void feedGpsLine(char *line); // defined in the UBX parser section below

// ----------------------------------------------------------------------------
// Demo mode: simulate the RAW sensors instead of faking final values.
// The hardware reads below are swapped for synthetic raw values (ADC counts,
// hall pulses and a synthetic GPS NMEA stream), so the
// ENTIRE real processing pipeline runs unchanged on simulated data: EMA
// filters, fuel touch-table interpolation, NTC->temperature math, hall
// speed, GPS parse/fusion (HAL/GPS/G+H), odometer, fuel consumption and the
// acceleration timer. The only simulated outputs are the raw readings
// themselves.
// ----------------------------------------------------------------------------

// Steady 20°/s course rotation for the synthetic GPS stream.
static float demoSimCourseDeg(unsigned long t) {
  return fmodf((float)t * 0.02f, 360.0f);
}

// Scripted drive cycle - the single source of truth for hall + GPS + all
// speed consumers. 0-8s: accelerate 0 -> ~55 km/h (crosses ACCEL_TARGET_SPEED
// well before the ACCEL_MAX_TIME cap, so the accel timer finishes with a real
// time). 8-60s: cruise climbing to ~95 km/h with ripple. 60-85s: brake to
// standstill. 85-90s: idle stop (accel timer re-arms, tank refuels). Then the
// loop restarts.
static float demoSimSpeedKmph(unsigned long t) {
  float phase = fmodf((float)t, 90000.0f);
  float v = 0.0f;
  if (phase < 8000.0f) {
    v = 55.0f * (phase / 8000.0f);
  } else if (phase < 60000.0f) {
    float p = phase - 8000.0f;
    v = 55.0f + 40.0f * (p / 52000.0f) + 5.0f * sinf(p / 4500.0f) +
        2.0f * sinf(p / 800.0f);
  } else if (phase < 85000.0f) {
    v = 95.0f * (1.0f - (phase - 60000.0f) / 25000.0f);
  }
  return (v < 0.0f) ? 0.0f : v;
}

// Inverse of the fuel sender chain: the raw ADC count processFuelSensor() would
// have to see for a desired level (issue #18). The level goes back through the
// same ohm table the real sender is read against, so demo mode exercises the
// production path instead of bypassing it. The excitation resistor cancels out of
// the code (code = 4095 x R / (R + R_exc)), so the simulation follows whatever
// ohm range and tank table is configured.
static int demoCodeForFuelLevel(float level) {
  int n = constrain(FUEL_TOUCH_POINTS, 2, MAX_TOUCH_POINTS);
  float l = constrain(level, 0.0f, (float)(n - 1));
  int i = (int)l;
  if (i >= n - 1) i = n - 2;
  float frac = l - (float)i;
  float ohms = fuelCalOhms[i] + frac * (fuelCalOhms[i + 1] - fuelCalOhms[i]);
  float rexc = (float)constrain(FUEL_EXC_RES_OHM, 1, 1000000);
  return constrain((int)(4095.0f * ohms / (ohms + rexc) + 0.5f), 0, 4095);
}

// Inverse of the NTC divider math: the raw ADC count that processTemperature-
// Sensor() would convert into the given degrees C. Kept clear of the
// 100/4000 "sensor fault" clamp.
static int demoAdcForTempC(float c) {
  // The model (before the NTC_TEMP_OFFSET bias) must yield c - NTC_TEMP_OFFSET,
  // so that processTemperatureSensor() shows exactly c.
  float cModel = c - NTC_TEMP_OFFSET;
  float tKelvin = cModel + 273.15f;
  float r = NTC_R25 * expf(NTC_BETA * (1.0f / tKelvin - NTC_INV_ROOM_KELVIN));
  float vOut = 3.3f * r / (r + NTC_R_BALANCE);
  int adc = (int)(vOut / ADC_VOLTS_FACTOR);
  return constrain(adc, 150, 3900);
}

// Inverse of the battery divider formula (processBatterySensor).
static int demoAdcForBatteryVoltage(float v) {
  int adc = (int)((((v - BATTERY_OFFSET) / (ADC_VOLTS_FACTOR * BATTERY_SCALE)) + 0.5f));
  return constrain(adc, 0, 4095);
}

// Simulated distance accumulated by the REAL odometer math (hall pulses and
// GPS movement). Kept separate from totalDistanceKm so demo mileage is
// display-only and can never reach NVS (see updateGPSOdometer).
static double demoOdoKm = 0.0;

// History of the last accepted hall pulse intervals (ring, fixed capacity).
// A single spurious pulse on the hall pin (EMI, bounce, passing magnet)
// used to land in hallPulseIntervalUs and briefly report several hundred
// km/h: with the default 1650 mm tire one 30 ms noise blip is 198 km/h.
// getHallSpeed() takes the median of the last HALL_MEDIAN_SAMPLES entries
// (WebUI-tunable; 1 = raw single interval, zero lag) so a corrupt blip can
// no longer move the reading unless a majority is corrupt. The real ISR
// and the demo simulator below both append through this ring.
static const unsigned int HALL_MEDIAN_MAX = 31; // ring capacity (compile-time)
static volatile unsigned long
    hallIntervalHist[HALL_MEDIAN_MAX] = {0};
static volatile unsigned int hallHistWriteIdx = 0;

// Hall filter-chain counters (P1 instrumentation). The ISR owns the raw edge
// count; every later layer is counted in processHallEdges() on the sensor task
// (issue #30). They answer one question with data: at what layer does the parked
// ignition EMI die, and does anything reach the accepted stage while the wheel
// is stationary? Read from gpsTask as per-interval deltas.
volatile unsigned long hallDbgEdges = 0;      // every ISR entry (both transitions)
volatile unsigned long hallDbgL1Reject = 0;   // measured pulse width < HALL_PULSE_MIN_US
volatile unsigned long hallDbgDebounce = 0;   // gap < DEBOUNCE_US
volatile unsigned long hallDbgL2Reject = 0;   // anti-collapse baseline reject
volatile unsigned long hallDbgGuardReject = 0; // HALL_PERIOD_GUARD reject
volatile unsigned long hallDbgL3Purge = 0;    // standstill branch taken
volatile unsigned long hallDbgUnconfirmed = 0; // accepted edge held as candidate
volatile unsigned long hallDbgAccepted = 0;   // edge published to the speed path
volatile unsigned long hallDbgRingDrop = 0;   // edge dropped because the ring was full

static const int HALL_DBG_N = 9;
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

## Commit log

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2026-07-21 Dashboard improvements and GPS LED fix
    [config.cpp, dashboard.h, gfx.cpp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]
2026-07-23 Implement BZGNSS P25 Pro GNSS module support (NMEA, 115200 baud) and QMC5883L compass via I2C
2026-07-23 Add CPU usage monitoring with real-time bar in web UI
    - Measure CPU usage via Xtensa ccount register (inline assembly)
    - Expose cpu_usage field in /api/perf endpoint
    - Add CPU usage bar to perf monitor panel with color-coded thresholds
    - Fix CPU frequency change breaking WiFi by enforcing 240 MHz when WiFi is active
    [dashboard.h, main.cpp, sensors.cpp]
2026-08-23 Add live fuel sensor raw ADC reading to WebUI, bump version to 1.3.1
2026-08-25 Fix hall speed spikes, add tunable filters, bump to 1.3.2
    [config.cpp, dashboard.h, main.cpp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]
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2026-08-26 Fix log ring buffer race with spinlock
    [dashboard.h, main.cpp]
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2026-09-01 Fix stale ignition-sense pin refs (GPIO34 → GPIO4) in README
2026-09-17 Reset trip distance on auto-refuel so post-refuel km/L is fresh
    [sensors.cpp]
2026-09-17 Auto-retry throttled OTA checks with live countdown in WebUI
2026-09-17 Fix refuel km/L and mDNS rebind, OTA auto-retry, bump to 1.3.4
    [config.cpp]
2026-09-19 Remove compass/heading feature from firmware (sensor, HUD, API, NVS)
2026-09-19 Remove compass/heading UI and calibration workbench from WebUI
2026-09-20 Migrate build to arduino-esp32 3.3.12 via pioarduino platform
2026-09-20 Remove capacitive fuel touch sensor, neutral gauge until resistive swap
    [dashboard.h, sensors.cpp]
2026-09-21 Use multi-pulse hall speed window, tighten period guard to 8x
    [config.cpp, sensors.cpp]
2026-09-21 Add Speed Source dropdown, drop GPS_ONLY_MODE, fix fusion 0-lock
    [config.cpp, dashboard.h, sensors.cpp]
2026-09-21 Fix hall sensor standstill deadlock, eliminate speed spikes, and rework sensor fusion
    [dashboard.h, sensors.cpp]
2026-09-21 Add NIGHT_BACKLIGHT param and fix audit code hygiene items
    [config.cpp, dashboard.h, main.cpp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]
2026-09-22 Eliminate hall speed spikes with physical acceleration guard, true median filter, and fusion cross-validation
2026-09-22 Update README.md changelog and speed architecture with physical guard and median filter
2026-09-22 Fix hall acceleration lag: purge standstill history, pure integer ISR, and 1.5x decay threshold
    [config.cpp, sensors.cpp]
2026-09-25 Implement 5-layer Hall defense pipeline, anti-collapse baseline, and physical slew-rate limiter
2026-09-28 Fix odometer double-count and stale GPS anchor freeze
    [sensors.cpp]
2026-09-28 Publish mutex-guarded GPS fix snapshot for all consumers
    [dashboard.h, main.cpp, sensors.cpp]
2026-09-28 Confirm standstill Hall pulses, add odometer drift diagnostic
    [sensors.cpp]
2026-09-28 Release V1.3.8: odometer accuracy fixes, bump to 1.3.8
    [config.cpp]
2026-09-28 Add Hall filter-chain counters and 1 Hz chain telemetry
2026-09-28 Gate Hall speed behind confirmed roll, wire period guard
2026-09-28 Floor NVS odometer retries, document V1.3.8 re-release fixes
    [sensors.cpp]
2026-09-29 Validate AP_PASSWORD length, surface SoftAP startup failure (fixes #45)
    [config.cpp]
2026-09-29 Bump to 1.3.9, document signed OTA flow and release assets
2026-09-29 Clamp digit-count config params to UI cell arrays (Closes #6)
2026-09-29 Send both UBX length bytes so GNSS recovery frames are valid (Closes #11)
2026-09-29 Gate GPS fix on gnssFixOk flag, not the time-validity bit (Closes #12)
    [sensors.cpp]
2026-09-29 Clamp the panel SPI clock band so a bad speed can't blank it (Closes #13)
2026-09-29 Store weather text in fixed arrays, not Strings (Closes #8)
    [dashboard.h]
2026-09-29 Align the README pinout matrix with the pin defines in code
2026-09-29 Sync the README hardware table with the display and backlight pin setup
2026-09-29 Clamp every numeric config param to a known-good band (Closes #21)
2026-09-29 Route the backlight through one clamped helper (Closes #20)
2026-09-29 Add GPIO25 trip-reset button, drop auto refuel reset (Closes #17)
    [config.cpp, dashboard.h, main.cpp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]
2026-09-29 Debounce power sense, sleep 10 s after power loss (Closes #26)
2026-09-29 Stamp Hall edges in the ISR, filter on the task (Closes #30)
2026-09-30 Read fuel from a marine resistive sender (Closes #18)
2026-09-30 Verify CPU freq switches, bound frame rate (Closes #34 #35 #36)
2026-09-30 Wire SAT_DIGITS, document advance-based text bounds (Closes #41 #44)
2026-09-30 Bump to 1.4.0 with the issue-sweep changelog
    [config.cpp]
2026-09-30 Fix WiFi search stuck on first SSID, search forever by default
    [config.cpp, dashboard.h, main.cpp]
2026-09-30 Fix inverted NVS write check, seed wiping SSIDs, stale WiFi list
    [config.cpp, dashboard.h, main.cpp]
2026-09-30 Name the NVS keys that fail to save, log the NVS entry budget
    [config.cpp, dashboard.h]
2026-09-30 Enlarge NVS to 80 KB, save only changed values
    [partitions.csv]
2026-10-01 Require BOOT release+rehold for factory reset, spare odometer
    [main.cpp]
2026-10-01 Add phone-style WiFi picker: join/forget, scan list, slot rotation
2026-10-01 Document WiFi picker endpoints, slot rotation and attempt window
2026-10-01 Wire the WiFi overwrite chooser to the picker click handler
2026-10-01 Fix TX power enum bug, always search WiFi, drop three params
    [config.cpp, dashboard.h]
2026-10-01 Cut WebUI paragraphs, unify card titles, notes and buttons
2026-10-01 Give dropdowns the page's own look and pin lists to their controls
2026-10-01 Localize weather city name when no GPS fix, keep UTF-8 cuts safe
    [dashboard.h]
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2026-10-01 Fix overlay font fallback, weather card margins, battery axis
    [dashboard.h, gfx.cpp]
2026-10-01 Regroup settings cards, poll at 1 Hz, show power-off in seconds
2026-10-02 Revert the VLW font loader rewrite pending the overlay fix
    [gfx.cpp]
2026-10-02 Revert commit ccd062a in full: font, weather margins, battery
    [dashboard.h, gfx.cpp]
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2026-10-02 Centre the battery icon body on the readout axis (#48)
2026-10-03 Add host-side harness reproducing WebUI live-poll stalls
2026-10-03 Add GET /api/live single-snapshot endpoint for 1 Hz WebUI reads
2026-10-03 Poll WebUI live reads as one 1 Hz request, never stacking sockets
2026-10-03 Document /api/live, the 1 Hz poll lane and the new perf timings
2026-10-03 Add on-device live-poll cadence mode to the verification harness
2026-10-07 Add KiCad PCB generator with courtyard/keepout placement checks
    [dashboard-plusplus-carrier.kicad_pcb]
2026-10-08 Clear carrier PCB DRC errors, fix silkscreen rules, DIN965 holes
    [dashboard-plusplus-carrier.kicad_pcb]
2026-10-08 Fix footprint library warnings, add project file and local lib
    [dashboard-plusplus-carrier.kicad_pcb]
2026-10-08 Give regenerated boards stable uuids, sync KiCad project files
    [dashboard-plusplus-carrier.kicad_pcb]
2026-10-08 Add plain-English pinout sheet for the board layout
2026-10-11 Rebuild carrier placement from CAD geometry, DRC clean
2026-10-11 Convert carrier to SMD parts, edge JSTs, real DevKit pitch
2026-10-11 Add rule 30: KiCad DRC is the referee for PCB work
2026-10-11 Move bulk caps C1/C3 to B.Cu, extend carrier 10 mm west
2026-10-12 Store bottom-face footprints the KiCad way; fixes 3D body offset
2026-10-12 Mirror underside JST-PH shells so they mate off the board edge
2026-10-12 Move build-notes text block below the board outline
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2026-10-12 Make the display socket 1x14 to match the drawing's 35 mm slot
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2026-10-12 Fix C2/D2 pad-role wording, re-measure gaps from KiCad output
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2026-10-13 Shorten test-point silks to IGN HALL BAT FUEL GND on one line
2026-10-13 Move Q1 F1 D1 R1 4.10 mm south, shift D2's silk label clear
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2026-10-13 Move F1 4.41 mm south, centre TP row east on x 61.15
2026-10-13 Move XT30 +12V silks west, centre both polarity labels on pad row
    '+12V' now hangs west of J1 next to the DC_IN pad it names (ink x 12.85-16.15), 'GND' east of the GND pad (x 29.35-31.75); both ink lands at y 13.54-14.44, centred on the connector's y centre (pads y 13.99). 1.00 mm clear of J1's courtyard, 2.20 mm clear of each pad, 1.94 mm north of the module's IN+/IN- row. DRC: 0 violations, 0 footprint errors, 115 unconnected (baseline).
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2026-10-14 Measure KiCad model draw rules, fix F1 clip frame, add frame guard
2026-10-14 Fix 3D body frame for F1 clip, add on-board render placement check
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2026-10-15 Turn J3 180 deg to the module's pin numbering, name all 14 pads
2026-10-15 Put J3 back to pad 1 = VCC north, print TFT pin names flat
2026-10-15 Move J3 VCC to the south pad, split antenna note in two
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2026-10-16 Price wall cuts by leg length, pay debts depth-first: unrouted 3 -> 1
2026-10-16 Audit routing off the copper, not the books; weld cuts, no dup tracks
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2026-10-17 Pour the GND planes in the gate; raise plane clearance to 0.60
2026-10-17 Route the 4-layer stackup: IPC inner widths, In2 rails, via barrel rule
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2026-10-19 Add A4 stitched GND guards where measured (15% of sensed runs), pin crosstalk ratchet at 33; A5 re-route measured unshippable
    A5 (sensed nets first) was run as two experiments, not assumed: E1 brought BAT_SNS 180.4 -> 91.3 mm but left GND and DBG_RX cut and took the route-log quiet count from 40 to 277 item pairs; E2 gave B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
    A4 on the shipped routing: new scripts/guard_pcb.py emits a 0.20 mm GND fence (centre 0.55 + w/2 from the sensed centre line) only on >= 2.0 m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
2026-10-19 Add the ignition TVS on IGN_12's trunk (SMF4L33A, SOD-123FL); SMB fits nowhere at J17, routing bit-identical (2934.9 mm/271 vias, DRC 0/0/0, crosstalk 33)
2026-10-19 Add the sensor noise bench (/api/noisematrix): four normal-running runs, 4000 samples at 1 kS/s, mean/sigma/p-p in mV and ADC codes
2026-10-19 Add the noise bench card to the WebUI: run the sensor noise test and read the table on the device, no PC or serial needed
2026-10-20 Fix WiFi slot rotation to use the raw NVS slot (issue #60)
2026-10-20 Keep ambient calibration pairs valid (issue #64)
2026-10-20 Fix WiFi rotation, calibration and cross-core issues from the audit, bump to 1.4.4
2026-10-20 Fix cloud OTA restart after a mid-download stall, bump to 1.4.5
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2026-10-26 Label trips by drive start, fix light sensor unit in Live tab
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2026-10-27 Tolerate whitespace after numbers in vehicle records
    A pretty-printed or hand-edited row put a space between a number and the ',' or '}' that ends it; the number scan set swallowed the space and threw 'space inside a number', so the whole record decoded to null and a card the user named disappeared. The guard was protecting against '12 34', which the object parser still rejects a step later.
    Also pins that a foreign row's ips order is truncated as stored and re-derived by the next bindConnect, so a reversed list costs one staler probe, once.
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2026-10-28 Tag trips with the vehicle they belong to and filter the list
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2026-10-30 Own the trip button during OTA screens, add done/error frames
2026-10-30 Fix USB flash slot selection and stop the NVS page overwrite
2026-10-31 Drop the version label, tag each image, pin CAs for the pull path

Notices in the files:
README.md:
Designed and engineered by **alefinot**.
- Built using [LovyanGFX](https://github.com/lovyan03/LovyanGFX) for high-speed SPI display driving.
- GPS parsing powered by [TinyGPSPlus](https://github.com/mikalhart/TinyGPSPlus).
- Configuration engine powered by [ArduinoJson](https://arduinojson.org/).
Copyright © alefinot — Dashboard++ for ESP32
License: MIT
